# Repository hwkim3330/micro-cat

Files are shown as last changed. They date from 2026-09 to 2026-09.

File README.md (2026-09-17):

# MICRO CAT — Rev 1

**소유자 hwkim3330이 제작·판매를 목표로 개발하는 상업용 독자 설계 소형 두발 로봇.** 둥근 머리, 쉘과 한 몸인 귀, 말려 올라간 꼬리, 뒤로 길어진 앞발. Microduck의 14축 정책 인터페이스(61 관측 → 14 행동, 50 Hz)를 그대로 쓰되 기구·외장·서보 배치·전장 자리는 독자 설계입니다.

관련 저장소: [Micro X](https://github.com/hwkim3330/micro-x)(티렉스 계열, 같은 도구·같은 소유자) · [Micro Rex](https://github.com/hwkim3330/micro-rex)(원본 기구를 그대로 쓰는 **비상업** 비교 시험기) · [micro-cat-fly](https://github.com/hwkim3330/micro-cat-fly)(고정된 초파리 커넥톰으로 목표 방향 명령을 만드는 **비상업** 연구 저장소).

**현재 단계: Rev 1 구동 설계 · 디지털 검증. 실물 출력·조립·보행·내구 시험은 아직 없습니다. 판매 가능한 완제품이 아닙니다.**

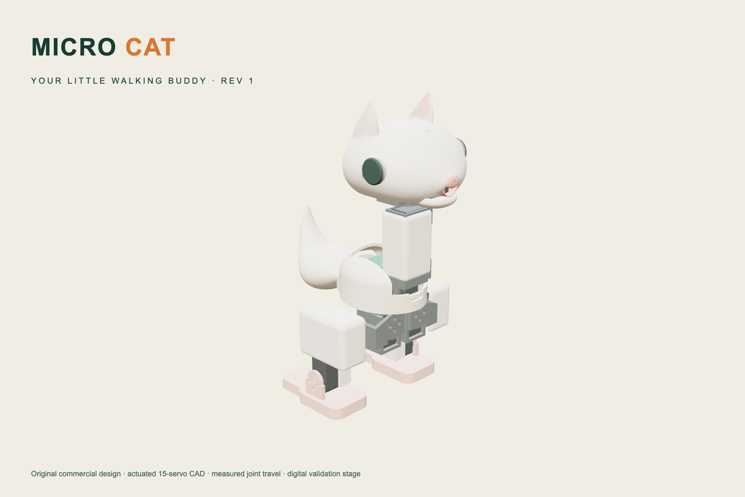
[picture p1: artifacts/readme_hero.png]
Micro Cat Rev 1 — 실제 CAD 렌더


| | |
|---|---|
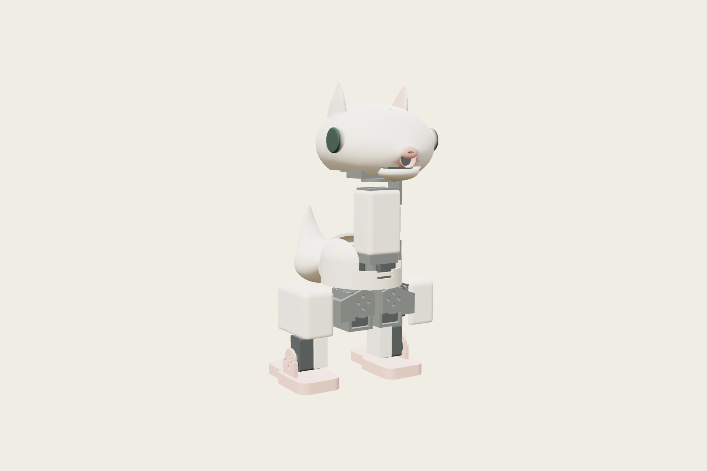
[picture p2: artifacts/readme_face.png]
얼굴
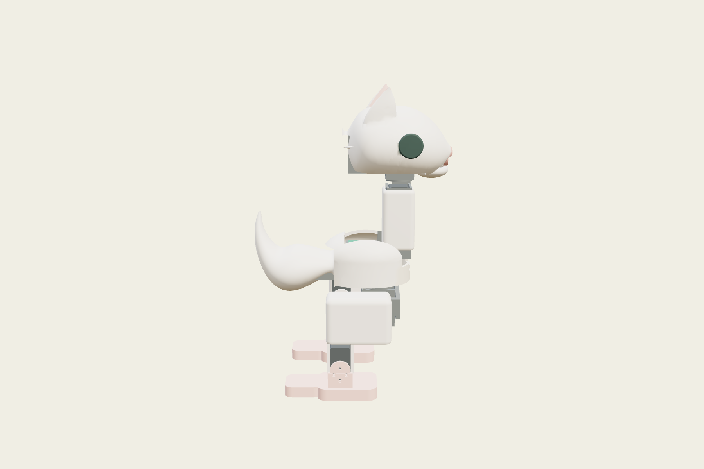
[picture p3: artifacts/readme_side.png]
측면
|  |  |

위 그림은 컨셉 일러스트가 아니라 **실제 CAD를 웹 뷰어로 띄워 촬영한 것**입니다(`tools/portrait.mjs`). 형상을 바꾸면 그림도 같이 바뀝니다.

[제품 페이지 · 3D 뷰어](https://hwkim3330.github.io/micro-cat/web/) · [학습 Lab](https://hwkim3330.github.io/micro-cat/web/lab.html) · [보행 실험](https://hwkim3330.github.io/micro-cat/web/simulator.html) · [설계](docs/DESIGN.md) · [조립](docs/ASSEMBLY.md) · [목표와 진행 기준](PROJECT_GOAL.md)

## 이 저장소가 주장하는 것과 주장하지 않는 것

주장하는 것은 **측정된 것뿐**입니다. 아래 표의 모든 숫자는 `artifacts/`의 JSON에서 `tools/report.py`가 자동으로 채워 넣으며, 모델 SHA256에 묶여 있어 형상을 바꾸면 검사 결과가 먼저 깨집니다. 문서에 손으로 적은 성능 숫자는 없습니다.

주장하지 않는 것: 실물 보행, 내구성, 원가 경쟁력. 특히 원가는 [docs/COST.md](docs/COST.md)에 기록된 대로 **15개 소매 서보 값만으로도 완제품 $399를 넘습니다.** 부품값으로 이기는 물건이 아닙니다.

<!-- measured:summary -->
| 항목 | 값 | 출처 |
|---|---|---|
| 출력 부품 | 20개, 474.7 g (PLA 꽉 찬 기준, 실제 인필은 더 가벼움) | `artifacts/parts.json` |
| 구매품 | 18개, 399.0 g (카탈로그) | 같은 파일 |
| 모델 총질량 · 무게중심 | 872.5 g, 무게중심 z 139.67 mm, 지지영역 여유 16.16 mm | `artifacts/balance.json` |
| 간섭 | 설계 자세 정적 겹침 0건 / 측정 가동 범위 안 스윕 충돌 0 | `artifacts/interference.json` |
| 출력성 | 20개 모두 220×220 침대, 최악 오버행 29 %, 침대 접촉 0 mm² 5개(right_upper_leg, left_upper_leg, skull, neck_sleeve, tail_cover)는 브림/서포트 필요 | `artifacts/printability.json` |
| 공식 가중치 (무수정) | 15회 중 15회 직립, 추종 게이트 6/15 통과 | `artifacts/compat_evaluation.json` |
<!-- /measured -->

## micro-x에서 바뀐 것

| | micro-x Rev C | Micro Cat Rev 1 | 이유 |
|---|---|---|---|
| 형상 | 둥근 머리 + 넓은 부리 | 둥근 두개골 + 짧은 입, 통짜 귀, 말린 꼬리 | 부리를 남기면 계속 오리로 읽힘 |
| 귀 | 없음 | 지붕에서 자라난 통짜 핀 | 별도 부품·얇은 목 없이 실루엣을 만드는 유일한 방법 |
| 앞발 | 평평한 바닥판만 | 같은 바닥판 + **1.0 mm 뜬 뒤꿈치 돌기** (뒤로 32 mm) | 아래 "가장 약한 축" 참조 |
| 고관절 브래킷 윗면 | 평면으로 절단 | **롤 축 ±0.35 rad 회전 포락선**으로 절단 | 평면이면 바깥 리브가 몸통 스커트에 걸려 롤이 +5.7°에서 멈춤 |
| 카메라 | x 70 | x 60 | 두개골을 122 → 108 mm로 줄이기 위해. 대가로 코 보어가 깔때기가 되어 실효 화각 약 60° |
| 발 접촉 박스 | 하드코딩 (x −52…2) | **발바닥 메시에서 산출** | 하드코딩이면 늘린 발이 물리 모델에 반영되지 않음 |

## 가장 약한 축은 "뒤로 넘어짐"이었습니다

HOME 자세에서 무게중심이 지지영역을 벗어나기까지의 정적 각도입니다(`tools/tip_study.py`, 강체·정적·접촉 모델 없음).

<!-- measured:tip -->
| | **Micro Cat** | **Microduck (원본)** | Micro X |
|---|---|---|---|
| **뒤로 기울기** | 17.65° | 8.5° | 5.5° |
| 앞으로 기울기 | 19.25° | 13.25° | 18.0° |
| 옆으로 기울기 | 25.25° | 23.8° | 24.9° |
| 무게중심 높이 (mm) | 135.7 | 141.1 | 138.0 |
| 질량 (g) | 872.5 | 737.2 | 834.3 |

`tools/tip_study.py`: 기울기마다 몸을 회전시켜 바닥에 내려놓고 접촉점을 다시 계산합니다. 원본은 HOME에서 **발바닥이 평평하지 않아** 뒤꿈치 선으로 서 있고, 무게중심이 그 선보다 21 mm 앞에 있어 발끝이 닿을 때까지 앞으로 넘어갑니다. 표의 값은 그렇게 안정된 자세부터 넘어질 때까지의 각도입니다. 강체·정적이며 접촉 강성·마찰·동역학은 없습니다.
<!-- /measured -->

머리가 무겁고 발이 앞으로만 길어서 뒤쪽 지지 거리가 짧습니다. 대응은 바닥판 뒤 32 mm까지 뻗은 **1.0 mm 떠 있는 뒤꿈치 돌기**입니다 — 평지에서는 안 닿고 뒤로 8° 기울면 닿습니다. 바닥판 자체는 기준 발과 같은 58 mm이고, 걸을 때 접촉 면적이 늘지 않습니다.

<!-- measured:spur -->
| 뒤꿈치 돌기 높이 | 맞물림 각도 | 뒤로 기울기 | 여유 |
|---|---|---|---|
| no spur | — | 4.5° | — |
| 0.5 mm | 7.1° | 17.6° | +10.5° |
| 1.0 mm | 7.98° | 17.65° | +9.7° |
| 1.5 mm | 8.85° | 17.7° | +8.8° |

맞물림 각도 = 돌기가 바닥에 닿기 시작하는 뒤쪽 기울기. 여유 = 닿은 뒤로도 더 기울 수 있는 각도이며, **음수면 닿기 전에 넘어져서 돌기가 아무 일도 하지 않습니다.**
<!-- /measured -->

여유가 음수면 **닿기 전에 넘어져서 효과가 0**입니다. 실제로 돌기를 24 mm로 잡았을 때 1.5 mm는 여유 −7.1°로 아무 일도 하지 않았고, 출하하려던 1.0 mm는 그 한 칸 아래였습니다. 32 mm로 늘려 세 높이 전부 여유 9° 이상을 확보했습니다. 이번 설계에서 유일하게 취향이 아니라 측정에 근거한 변경입니다.

### 속도·회전 숫자는 믿지 마세요

<!-- measured:harness -->
| 모델 | 전진 명령 추종 (최대) | 회전 명령 추종 (최대) |
|---|---|---|
| microduck_reference | 45 % | 9 % |
| micro_cat | 25 % | 1 % |

기준 로봇 자신이 자기 명령을 못 따르므로, **이 하네스의 절대 속도·회전 숫자는 설계 근거로 쓸 수 없습니다.** 같은 하네스 안에서의 모델 간 상대 비교만 의미가 있습니다.
<!-- /measured -->

주의: 머리 전장을 몸통으로 옮기는 식의 "무게를 낮춘다" 대응은 몸통 질량중심이 발 중심보다 뒤에 있으면 오히려 뒤쪽을 악화시킵니다. 무게 재배치는 반드시 몸통 **앞쪽**이어야 하고, 뒤꿈치 연장과 세트로만 의미가 있습니다.

## 측정된 가동 범위

`tools/travel.py`가 관절마다 0.05 rad씩 돌려 가며 정확한 STEP 불리언으로 충돌을 찾은 값이고, 그대로 MuJoCo 관절 한계가 됩니다. 좌우가 다른 것은 브래킷이 좌우 대칭이라 회전 방향에 따라 닿는 곳이 다르기 때문입니다.

<!-- measured:travel -->
| 관절 | 왼쪽 | 오른쪽 |
|---|---|---|
| 고관절 요 | -29.8° … +29.8° | -29.8° … +29.8° |
| 고관절 롤 | -22.9° … +20.1° | -20.1° … +22.9° |
| 고관절 피치 | -90.0° … +51.6° | -51.6° … +90.0° |
| 무릎 | -90.0° … +63.0° | -63.0° … +90.0° |
| 발목 | -31.5° … +31.5° | -31.5° … +31.5° |
| 목 피치 | -11.5° … +22.9° | (단일) |
| 머리 피치 | -48.7° … +54.4° | (단일) |
| 머리 요 | -114.6° … +114.6° | (단일) |
| 머리 롤 | -5.7° … +8.6° | (단일) |
| 턱 | +0.0° … +5.7° | (단일) |

탐색 상한: 고관절 요 ±30°, 고관절 롤 ±23°, 고관절 피치 ±90°, 무릎 ±90°, 발목 ±90°, 목 피치 ±60°, 머리 피치 ±90°, 머리 요 ±115°, 머리 롤 ±25°, 턱 ±40°. 상한에 도달한 값은 기구가 아니라 탐색 범위가 끝난 것입니다.
<!-- /measured -->

## 설계 개요

- **관절**: 좌우 고관절 요·롤·피치, 무릎, 발목(10) + 목 피치, 머리 피치·요·롤(4) + 턱(1).
- **피벗·축**: `engineering/functional_layout.json` (기준 로봇을 qpos 0에서 측정한 기능 치수). 서보 몸체 방향만 두 곳에서 바꿨고 이유를 같은 파일에 적었습니다.
- **서보**: XL330급. 인터페이스 치수와 발주 전 확인 항목은 `engineering/actuator_interface.json`. 케이스 홀 패턴은 아직 모델에 없습니다.
- **패키징**: 2S 18650급 배터리는 꼬리 커버 안, 보드(최대 50 × 27 mm)는 고관절 서보 위 데크, 카메라는 코 안.
- **떨어질 부품 없음**: 귀·눈·코는 전부 쉘과 한 몸이고 도색으로 마감합니다. 손·발톱·수염 없음.
- **설계 자세**는 `qpos = 0`(다리를 곧게 편 자세)이라 모든 관절 축이 X·Y·Z에 정렬되고 브래킷이 평평하게 출력됩니다. 정책의 HOME 각도는 기구에 굳히지 않습니다.

## 재생성

```sh
uv venv .venv && uv pip install --python .venv/bin/python -r requirements.txt
.venv/bin/python cad/build.py          # 20개 부품 STEP/STL/GLB + artifacts/parts.json
.venv/bin/python tools/travel.py       # 실측 가동 범위 (수십 분)
.venv/bin/python cad/compat_model.py   # models/micro_cat_14.xml, rig.json, 제어 계약
.venv/bin/python tools/interference.py # 정적 겹침 + 관절별 스윕
.venv/bin/python tools/printability.py # 침대 적합·오버행·접촉 면적
.venv/bin/python tools/balance.py tools/tip_study.py
.venv/bin/python tools/report.py       # 위 결과를 README와 docs/DESIGN.md에 반영
```

정책 평가는 별도 환경입니다:

```sh
uv venv --python 3.12 .venv-policy && uv pip install --python .venv-policy/bin/python -r requirements-policy.txt
.venv-policy/bin/python tools/fetch_compat.py
MUJOCO_GL=disable .venv-policy/bin/python tools/evaluate_compat.py --seconds 10 --seeds 3
```

## 권리

원 설계·CAD·도면·문서: © 2026 hwkim3330, 무단 제조·재배포 금지. 소프트웨어(`tools/`, `runtime/`, `tests/`, `web/`): MIT. 자세한 범위는 [LICENSE](LICENSE)와 [THIRD_PARTY.md](THIRD_PARTY.md).

**Microduck 하드웨어 파일은 이 저장소에 없습니다.** 관절 피벗·축은 출처를 밝힌 기능 치수 측정값이며, 원본 CAD·STL·바디 변환·학습 가중치는 포함하지 않습니다. 원본 기구를 그대로 쓰는 비상업 시험기는 [micro-rex](https://github.com/hwkim3330/micro-rex)에 분리되어 있습니다.

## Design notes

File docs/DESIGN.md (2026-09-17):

# Micro Cat Rev 1 — 설계

좌표계는 mm, X 앞, Y 왼쪽, Z 위, 바닥 Z=0, 몸통 기준 프레임 Z=120입니다. 생성기는 `cad/build.py`, 배치는 `cad/layout.py`, 서보 인터페이스는 `cad/servo.py`, 측정값은 `engineering/functional_layout.json`입니다. 이 문서의 측정 표는 `tools/report.py`가 `artifacts/`에서 채웁니다.

## 물려받은 기구 원칙 (micro-x에서 검증된 것)

1. **설계 자세는 `qpos = 0`** — 다리를 곧게 편 자세에서 치수를 잽니다. HOME(다리가 굽은 자세)에서 재면 모든 피벗 축이 5° 기울어 브래킷마다 사선 형상이 필요합니다. 설계 자세를 곧게 두면 **모든 관절 축이 X·Y·Z에 정렬**되고 브래킷이 단순한 직육면체 조합이 되어 서포트 없이 평평하게 출력됩니다. 정책의 HOME 각도는 기구에 굳히지 않고 그냥 관절 각도로 둡니다.
2. **서보 고정은 단면 방식** — 서보 몸체가 한쪽 링크의 U자 채널에 들어가고, 이웃 링크는 혼에 볼트로 붙는 판 한 장입니다. 관절마다 판 두 장으로 감싸는 클레비스보다 얇고 가볍습니다.
3. **가동 범위는 측정** — `tools/travel.py`가 관절마다 0.05 rad씩 돌려 가며 정확한 STEP 불리언으로 충돌을 찾고, 그 값이 그대로 MuJoCo 관절 한계가 됩니다.

## 구성

| 부위 | 내용 |
|---|---|
| 몸통 | 섀시(바닥판·고관절 요 서보 박스 2개·전장 데크·배터리 트레이) + 알 모양 쉘 |
| 꼬리 | 중심선 접평면 위 단면 7개 로프트. 뒤로 나갔다가 위로 말려 올라가며, 앞쪽 곧은 구간이 배터리 커버 |
| 다리 | 요·롤 브래킷 → 고관절 브래킷 → 허벅지 쉘 → 종아리 → 앞발 |
| 목 | 두 서보가 세로로 쌓인 튜브 + 둥근 커버 |
| 머리 | 요크 → 머리 프레임(머리 롤 + 턱 서보, 카메라 벽, 두개골 보스) → 두개골 로프트 + 아래턱 |

## 고양이로 보이게 만든 것

머리는 **단면 9개 로프트 + 짧은 입 타원체**입니다(x −30…78, 폭 110, 높이 62). micro-x의 부리를 남기면 계속 오리로 읽히기 때문에 부리를 없애고 앞을 뭉툭하게 닫았습니다. 머리를 짧게 만들려고 카메라를 x 70 → 60으로 10 mm 뒤로 옮겼고, 그 대가로 **코 보어가 14 mm 깔때기가 되어 실효 화각이 약 60°**로 모듈 정격보다 좁습니다. 이건 취향이 아니라 맞바꾼 성능이므로 BOM에도 적어 두었습니다.

**귀는 별도 부품이 아닙니다.** 지붕 안쪽(z 276)에서 시작해 z 310까지 올라가는 통짜 테이퍼 핀이라 부러질 목이 없습니다. 안쪽 면은 도색입니다. 눈도 쉘에서 8 mm 뿌리로 솟은 Ø23 버튼이고(테두리가 수직이라 도색 경계가 선명), 코는 렌즈 후드 둘레 도색입니다. **떨어질 부품은 하나도 없습니다** — 수염·발톱·손도 없습니다.

## 가장 약한 축은 뒤로 넘어짐이었습니다

HOME 자세에서 무게중심이 두 발 지지영역을 벗어나기까지의 정적 각도입니다(`tools/tip_study.py`). 강체·정적이고 접촉·마찰·동역학은 없습니다.

<!-- measured:tip -->
| | **Micro Cat** | **Microduck (원본)** | Micro X |
|---|---|---|---|
| **뒤로 기울기** | 17.65° | 8.5° | 5.5° |
| 앞으로 기울기 | 19.25° | 13.25° | 18.0° |
| 옆으로 기울기 | 25.25° | 23.8° | 24.9° |
| 무게중심 높이 (mm) | 135.7 | 141.1 | 138.0 |
| 질량 (g) | 872.5 | 737.2 | 834.3 |

`tools/tip_study.py`: 기울기마다 몸을 회전시켜 바닥에 내려놓고 접촉점을 다시 계산합니다. 원본은 HOME에서 **발바닥이 평평하지 않아** 뒤꿈치 선으로 서 있고, 무게중심이 그 선보다 21 mm 앞에 있어 발끝이 닿을 때까지 앞으로 넘어갑니다. 표의 값은 그렇게 안정된 자세부터 넘어질 때까지의 각도입니다. 강체·정적이며 접촉 강성·마찰·동역학은 없습니다.
<!-- /measured -->

머리가 전체 질량의 큰 몫을 차지하는데 발은 앞으로만 길어서, 뒤쪽 지지 거리가 앞쪽의 3분의 1도 되지 않습니다.

**처음 시도(바닥판을 뒤로 16 mm 연장)는 폐기했습니다.** 접촉 패치가 길어지면 회전을 방해하고(`artifacts/foot_length_sweep.json`), 무엇보다 뒤쪽 지지가 늘어나는 만큼 바닥에 항상 닿아 있어야 해서 얻는 게 없습니다.

채택한 것은 **뜬 뒤꿈치 돌기**입니다. 바닥판은 기준 발과 같은 58 mm(x −54…4)로 두고, 그 뒤 32 mm까지 뻗은 돌기(x −86…−50)를 바닥면보다 **1.0 mm 위**에 둡니다. 평지에서는 닿지 않고, 뒤로 8° 기울면 바닥에 닿아 그때부터 지지점이 됩니다.

<!-- measured:spur -->
| 뒤꿈치 돌기 높이 | 맞물림 각도 | 뒤로 기울기 | 여유 |
|---|---|---|---|
| no spur | — | 4.5° | — |
| 0.5 mm | 7.1° | 17.6° | +10.5° |
| 1.0 mm | 7.98° | 17.65° | +9.7° |
| 1.5 mm | 8.85° | 17.7° | +8.8° |

맞물림 각도 = 돌기가 바닥에 닿기 시작하는 뒤쪽 기울기. 여유 = 닿은 뒤로도 더 기울 수 있는 각도이며, **음수면 닿기 전에 넘어져서 돌기가 아무 일도 하지 않습니다.**
<!-- /measured -->

돌기 뒤쪽 길이가 이 설계의 핵심 변수입니다. 처음에는 24 mm로 잡았는데, 그때는 **1.5 mm 돌기가 닿기 전에 로봇이 먼저 넘어가서 효과가 정확히 0이었고**(여유 −7.1°), 출하하려던 1.0 mm는 그 바로 한 칸 아래였습니다. 무게중심이 조금만 움직여도 무용지물이 되는 자리입니다. 32 mm로 늘리자 세 높이 전부 여유 9° 이상으로 맞물립니다.

이 함정은 계산으로는 안 보입니다. 무게중심을 지지영역에 투영하는 기존 방식은 **닿지도 않는 돌기를 지지점으로 계산해서 효과가 있다고 답합니다.** 준정적 로킹 해석이라야 드러납니다.

남은 위험: 보행 중에 돌기가 바닥을 스치는지는 아래 이유로 아직 못 잽니다.

## 이 저장소가 속도·회전 숫자를 믿지 않는 이유

고정된 공식 추론 코드와 무수정 가중치로 **기준 로봇을 그 로봇 자신의 공식 씬에서** 돌린 결과입니다(`tools/harness_check.py`).

<!-- measured:harness -->
| 모델 | 전진 명령 추종 (최대) | 회전 명령 추종 (최대) |
|---|---|---|
| microduck_reference | 45 % | 9 % |
| micro_cat | 25 % | 1 % |

기준 로봇 자신이 자기 명령을 못 따르므로, **이 하네스의 절대 속도·회전 숫자는 설계 근거로 쓸 수 없습니다.** 같은 하네스 안에서의 모델 간 상대 비교만 의미가 있습니다.
<!-- /measured -->

기준 로봇이 전진 명령의 45 %, 회전 명령의 9 %밖에 못 따르고 1.0 m/s 명령에서는 2.1초에 넘어집니다. 그래서 이 하네스는 **직립·안정성 판정에는 쓰되, 속도·회전 추종을 설계 판단 근거로는 쓰지 않습니다.** 발 길이·뒤꿈치 스윕의 회전 숫자도 같은 이유로 참고용입니다.

반직관적인 점 하나: "머리 전장을 몸통으로 내려 무게중심을 낮춘다"는 대응은 몸통 질량중심이 발 중심보다 뒤에 있으면 **뒤쪽을 오히려 악화시킵니다.** 무게 재배치는 몸통 앞쪽이어야 하고, 뒤꿈치 연장과 세트로만 의미가 있습니다.

## 고관절 롤이 막혀 있던 이유

micro-x는 고관절 브래킷 윗면을 **평면**(z 114.5)으로 잘랐습니다. 그러면 롤을 줄 때 바깥 리브가 올라가 몸통 스커트 밑면(z 116)에 걸려 롤이 **+5.7°**에서 멈춥니다 — 카탈로그 ±23°와 무관하게, 그리고 문서에 적힌 ±17°와도 무관하게 실제로 그렇습니다.

Micro Cat은 윗면을 평면이 아니라 **롤 축을 중심으로 ±0.35 rad 회전시킨 섀시 바닥면의 하한 포락선**으로 깎습니다(`ROLL_SWEEP`). 브래킷은 조금 작아지지만 롤이 탐색 상한까지 열립니다.

## 측정된 가동 범위

<!-- measured:travel -->
| 관절 | 왼쪽 | 오른쪽 |
|---|---|---|
| 고관절 요 | -29.8° … +29.8° | -29.8° … +29.8° |
| 고관절 롤 | -22.9° … +20.1° | -20.1° … +22.9° |
| 고관절 피치 | -90.0° … +51.6° | -51.6° … +90.0° |
| 무릎 | -90.0° … +63.0° | -63.0° … +90.0° |
| 발목 | -31.5° … +31.5° | -31.5° … +31.5° |
| 목 피치 | -11.5° … +22.9° | (단일) |
| 머리 피치 | -48.7° … +54.4° | (단일) |
| 머리 요 | -114.6° … +114.6° | (단일) |
| 머리 롤 | -5.7° … +8.6° | (단일) |
| 턱 | +0.0° … +5.7° | (단일) |

탐색 상한: 고관절 요 ±30°, 고관절 롤 ±23°, 고관절 피치 ±90°, 무릎 ±90°, 발목 ±90°, 목 피치 ±60°, 머리 피치 ±90°, 머리 요 ±115°, 머리 롤 ±25°, 턱 ±40°. 상한에 도달한 값은 기구가 아니라 탐색 범위가 끝난 것입니다.
<!-- /measured -->

턱은 여전히 좁습니다. 턱 피벗이 머리 요크 앞면(x 39.4) 바로 옆이라 혼 판이 곧바로 요크에 닿습니다. 혼 판 폭을 20 → 13 mm로 줄여도 바뀌지 않았고, **요크를 다시 그려야 풀립니다.** 다음 개선 대상입니다.

머리 프레임을 그릴 때 주의: 앞쪽 빔과 두개골 앞 보스가 요크 앞면(x 39.4)에서 2 mm 이상 떨어져야 합니다. 처음 그렸을 때 보스를 x 42에 두어 **정지 상태에서 195 mm³ 겹쳤고, 머리 롤이 0°가 되었습니다.**

## 출력과 검증

<!-- measured:summary -->
| 항목 | 값 | 출처 |
|---|---|---|
| 출력 부품 | 20개, 474.7 g (PLA 꽉 찬 기준, 실제 인필은 더 가벼움) | `artifacts/parts.json` |
| 구매품 | 18개, 399.0 g (카탈로그) | 같은 파일 |
| 모델 총질량 · 무게중심 | 872.5 g, 무게중심 z 139.67 mm, 지지영역 여유 16.16 mm | `artifacts/balance.json` |
| 간섭 | 설계 자세 정적 겹침 0건 / 측정 가동 범위 안 스윕 충돌 0 | `artifacts/interference.json` |
| 출력성 | 20개 모두 220×220 침대, 최악 오버행 29 %, 침대 접촉 0 mm² 5개(right_upper_leg, left_upper_leg, skull, neck_sleeve, tail_cover)는 브림/서포트 필요 | `artifacts/printability.json` |
| 공식 가중치 (무수정) | 15회 중 15회 직립, 추종 게이트 6/15 통과 | `artifacts/compat_evaluation.json` |
<!-- /measured -->

부품마다 출력 방향이 `models/print/`에 고정되어 있습니다. 대부분의 브래킷은 면 하나를 침대에 붙이고 벽이 전부 수직이라 서포트가 필요 없습니다. 침대 접촉 면적이 0 mm²인 부품은 브림 또는 서포트가 필요합니다.

공식 가중치 시험의 전진 명령 추종 미달은 **원본 Microduck 모델에 같은 하네스를 돌려도 나타납니다**(micro-rex의 `tools/evaluate_policy.py`). 고양이 기구만의 결함으로 해석하지 않습니다.

## 남은 일

- 턱 가동 범위: 요크 재설계.
- 서보 케이스 홀 확인 후 몸체 고정 나사 추가, 케이블 경로(목·머리 4축, 다리 5축).
- IMU·마이크·스피커·전원 보드 배치(데크는 50 × 27 mm까지).
- 출력 공차 시편 → 다리 한 쪽 → 전체 조립 → 낙하·피로·발열 → 보행 시험.
- 공급업체 견적, DFM, 권리 검토.

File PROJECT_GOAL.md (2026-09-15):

# Micro Cat product design goal

Owner: hwkim3330. A commercial, independently designed cat-shaped companion biped that keeps
the Microduck 14-axis policy interface (61 observations to 14 actions at 50 Hz) so the public
pretrained weights load unchanged.

## Why a separate repository

- `micro-rex` vendors Microduck hardware files (CC BY-SA-NC) and therefore stays noncommercial.
  Nothing in this repository may depend on it.
- `micro-x` is the T-rex line. Three appearance revisions there were rejected as not cute enough
  and the cost study showed it could not undercut a $399 complete robot. Micro Cat restarts the
  appearance from a cat, and carries over only the parts of that work that were measured and held
  up: the design-pose layout, the single-sided servo mounting, and the measurement tools.
- This repository contains no Microduck CAD, STL, body transforms, trained policies or
  hardware-derived model data. Joint pivots and axes are attributed functional measurements.

## What is carried over, and what is new

Carried over from micro-x (same owner, same toolchain):
- design pose at `qpos = 0` (straight legs), so every joint axis is world-aligned and brackets print flat;
- servo held by a U-channel in one link driving a single horn plate on the next;
- measured, not declared, joint travel (`tools/travel.py`), printability, interference and balance tools;
- the CAD-derived 14-axis MuJoCo model and the Lab/simulator web stack.

New in Micro Cat:
- round cat cranium with a short muzzle, solid printed ears, nose lens hood, button eyes;
- a tail that curls up and still works as the battery cover;
- paws whose soles reach 16 mm further back than the reference foot. This is the one change
  driven by a measurement rather than by taste: on the stock reference robot, backward tipping
  is the weakest static axis (6.7 deg, versus 11.9 forward and 23.0 lateral), and the aft support
  reach is what sets it. See `docs/DESIGN.md`.

## Acceptance and limits

- Every printable part is a valid closed CAD solid and a watertight mesh; the design pose has no
  exact-STEP overlaps; per-joint sweeps inside the measured travel are recorded.
- Servo interface dimensions are purchased-part data. Case hole pattern, cable exits and the
  voltage rail must be confirmed before ordering.
- Static CAD, simulated uprightness and ONNX loading are not walking acceptance. Acceptance needs
  measured velocity and yaw tracking, fall rates and reproducible training, then physical trials.
- The cost model uses retail servo pricing and stated assumptions. It is not a quote, and the
  recorded conclusion from micro-x still stands: 15 retail XL330-class servos alone exceed the
  price of a complete $399 robot. Anything sold here has to be justified on something other than
  beating that number on parts cost.

## Completion ledger

- [x] Rev 1 actuated cat CAD: 20 printed parts, 15 servo envelopes, battery/board/camera placement
- [ ] Measured travel, interference, printability and balance regenerated for the cat geometry
- [ ] CAD-derived 14-axis model; unchanged official weights evaluated on it
- [ ] Product page, Lab and simulator rebuilt on the cat rig
- [ ] Servo case retention and cable routing
- [ ] Printed coupons, one leg, full assembly; fit, endurance, drop and thermal tests
- [ ] Walking acceptance in simulation, then on hardware
- [ ] Supplier quotes, DFM, market and rights review before any sale

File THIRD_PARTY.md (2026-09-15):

# Third-party software

- Three.js 0.180.0, MIT, bundled under web/vendor/three/. Upstream license retained as LICENSE. Source: https://github.com/mrdoob/three/tree/r180
- CadQuery 2.8.0 (Apache-2.0), Open CASCADE via cadquery-ocp, trimesh 4.11.1 (MIT), NumPy (BSD), ReportLab (BSD): build-time dependencies, not bundled in the website. Their licenses are not automatically assigned to original generated designs.
- Puppeteer 25.10.0 (Apache-2.0): test-time dependency.

No upstream Microduck mesh, CAD or hardware XML is included. Functional joint measurements are attributed in engineering/functional_interface.json. Pinned Apache-2.0 inference software and policy weights are fetched into the excluded local cache by tools/fetch_compat.py; engineering/policy_sources.json records hashes and license sources. The official mjlab training environment is installed separately under its own licenses. These software licenses do not relicense upstream hardware.

Camera mounting dimensions reference the Raspberry Pi Camera Module 3 Standard manufacturer drawing . No manufacturer drawing or CAD is bundled. rpicam-apps and ALSA utilities are external system dependencies, not distributed here. The original synthesized chirp and runtime source are MIT under the root LICENSE scope.

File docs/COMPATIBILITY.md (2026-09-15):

# 14축 정책 호환 검증 (Rev A)

목표는 **독자 설계 상업용 Micro Cat가 Microduck의 정책 인터페이스(61 관측 → 14 행동, 50 Hz)를 그대로 쓰는 것**입니다. 원본 CAD로 돌아가거나 비상업 하드웨어를 재라이선스하는 것이 아닙니다.

## 세 층

1. **Rev B CAD** (`cad/build.py`): 20개 출력 부품 + 15개 서보·배터리·보드·카메라 외형. 관절 피벗·축은 `engineering/functional_layout.json`(기준 로봇을 qpos 0에서 측정한 기능 치수)을 따르고 나머지는 새로 설계.
2. **CAD 기반 동역학 모델** (`cad/compat_model.py` → `models/micro_cat_14.xml`): 부품 메시에서 링크별 질량·질량중심·관성을 계산(PLA 꽉 찬 밀도 + 구매품 카탈로그 질량). 관절 한계는 추측이 아니라 `tools/travel.py`가 측정한 실제 가동 범위입니다. 몸통 프레임은 기준 로봇과 같은 120 mm 높이이고, HOME 기립 높이는 119.3 mm입니다. 이전의 원시 도형 연구 모델은 `models/archive/micro_cat_14_primitive_study.xml`로 보존.
3. **고정된 공식 추론 코드 + 가중치** (`runtime/compat_env.py`, `.cache/compat/`): 변경 없는 `alpha_walking.onnx`/`alpha_stand.onnx`와 BAM M6 XL330 모터 모델(kp 200, 7.4 V 재현 조건).

## 제어 계약

`engineering/control_interface.json`: 14 액추에이터 이름·순서, HOME 오프셋, 61 관측(자이로 3, 투영 중력 3, HOME 상대 관절 위치 14, 관절 속도 14, 이전 행동 14, 명령 13), 50 Hz 제어 / 200 Hz 물리. 목표 = HOME + 행동, 스케일 1. 턱은 15번째 수동 관절(정책 외)로 모델에 포함되며 `models/rig.json`이 qpos 배열 순서를 기록합니다.

Rev B의 관절 한계는 `engineering/joint_travel.json`의 측정값입니다: 고관절 요 -26°…+30°, 롤 -20°…+17°, 피치 -90°…+63°, 무릎 -90°…+63°, 발목 ±52°, 목 피치 -12°…+40°, 머리 피치 ±34°, 요 ±115°, 롤 ±17°, 턱 0°…+17° (좌우 비대칭). 정책이 그 이상을 명령하면 시뮬레이션에서 관절 한계에 걸립니다.

## 시험 프로토콜

`tools/evaluate_compat.py`: 정지, 전진 0.1 / 0.3 m/s, 회전 0.3 rad/s 명령 × 시드, 각 N초. 넘어짐 = 몸통 기울기 45° 초과 또는 높이 65 mm 미만. 1초 워밍업 후 몸체 좌표 속도 MAE. 통과 = 넘어짐 없음, 전진 MAE ≤ max(0.03, 명령의 25 %), 좌우 ≤ 0.03, 요 ≤ 0.10. 학습 체크포인트는 `--walking-policy`로 같은 프로토콜에 넣습니다(Lab의 "평가 실행").

## 현재 결과

- `artifacts/compat_evaluation.json`: CAD 기반 모델에 변경 없는 공식 가중치. 결과 요약은 Lab 14축 학습 탭의 첫 카드와 `README.md`에 있으며, 모델 SHA256이 파일에 묶여 있어 모델을 바꾸면 테스트가 실패합니다.
- `artifacts/compat_training.json`: 같은 액터를 CPU PPO로 짧게 이어 학습·ONNX 재내보내기 (파이프라인 검증).
- 이전 원시 연구 모델의 기록(`compat_heldout_evaluation.json`, `training_500.json`, `trained_500_evaluation.json`, `official_recipe_x_validation.json`)은 아카이브 모델 SHA256에 묶여 보존됩니다.

원본 Microduck 모델에 같은 프로토콜을 돌린 비교값은 [micro-rex](https://github.com/hwkim3330/micro-rex)의 `tools/evaluate_policy.py`가 만듭니다. 두 결과를 나란히 읽어야 "가중치 호환"의 의미가 정해집니다: 원본에서도 이 하네스의 전진 명령 추종은 미달이므로, X의 미달을 X 기구만의 문제로 보지 않습니다.

## 재현

```sh
uv venv --python 3.12 .venv-policy && uv pip install --python .venv-policy/bin/python -r requirements-policy.txt
.venv-policy/bin/python tools/fetch_compat.py
.venv/bin/python cad/build.py && .venv/bin/python cad/compat_model.py
.venv-policy/bin/python tools/evaluate_compat.py --seconds 10 --seeds 3
.venv-policy/bin/python tools/train_compat.py --updates 10 --steps 256
.venv-policy/bin/python runtime/training_service.py   # Lab에서 학습·평가·재생
```

실물 호환(전압 5 V 재보정, 실제 관성, 케이블, 접촉)과 생산 준비는 별도 미해결 과제입니다.

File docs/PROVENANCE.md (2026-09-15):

# Provenance and commercial boundaries

This is a newly initialized repository, not a fork of Microduck or the Micro Rex retrofit or the Micro X repository (same owner, shared tooling, independent geometry). `cad/build.py` constructs geometry from explicit dimensions using CadQuery primitives and lofts; it reads no external robot geometry. Body outlines, joint display pivots and part splits originate in this file. The developer previously inspected Microduck sources, so this is not represented as a formal clean-room legal process.

The old Micro Rex geometry stays in its separate repository. Its pinned upstream Microduck RL README states hardware designs are CC BY-SA-NC, without a version in that notice:
https://raw.githubusercontent.com/pollen-robotics/microduck_rl/2b25a48b08f1f17bc38c90bb03144c81fbd9ed07/README.md

No conversion of those rights to a commercial license is attempted. The general NC restriction is described by Creative Commons at https://creativecommons.org/licenses/by-nc-sa/4.0/ ; that page does not determine the unspecified version of the upstream notice.

Original design data including parametric CAD source is reserved for the owner under the root LICENSE. Software utilities and web application logic are MIT. Three.js is MIT and retains its upstream text. Public GitHub access is not an additional manufacturing grant. This is a chosen publication policy, not a legal opinion establishing ownership or freedom to operate. Micro Cat is a working name; trademark/design/patent searches and supplier rights review remain product launch gates.

## Supplier research, accessed 2026-09-08

- ROBOTIS XL330-M288 official manual: https://emanual.robotis.com/docs/en/dxl/x/xl330-m288/ . Used for candidate comparison only. No CAD copied.
- Waveshare ST3215 family product page: https://www.waveshare.com/product/modules/st3215-servo.htm . Listed family price $16.99–21.99, different voltage variants; not a negotiated quote or a validated actuator selection. Do not assume the same voltage/torque for every variant.
- FEETECH SCS0009 manufacturer PDF links were located but retrieval failed. No dimensional or torque claims from those unread files were used in this CAD.
- Pollen Robotics Robot HAT repository is Apache-2.0, unlike the noncommercial mechanical model: https://github.com/pollen-robotics/elec_RPI_Robot_HAT . Not bundled or integrated here.

None of the supplier names imply partnership, endorsement or manufacturing approval.

## Functional interoperability measurements

The separate 14-axis study uses joint pivots at HOME (rounded to 0.1 mm) and axes measured from the reference model. `engineering/functional_interface.json` records attribution and the source hash. These measurements are not claimed as exclusive original X artwork. X study surfaces, primitive links, masses and inertias are authored separately; no original hardware meshes or XML are redistributed as X. This is not a legal clearance opinion or relicensing of upstream hardware. The earlier P0-only provenance descriptions do not describe this separate dynamics study.

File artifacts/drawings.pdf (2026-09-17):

# MICRO CAT Rev 1 — printed part reference drawings

Actuated chibi cat; 14 policy joints + jaw. Millimetres. Design pose (straight legs). Assembly frame: X forward, Y left, Z up, floor Z=0, trunk frame Z=120. 20 printed parts (474.7 g solid PLA equivalent) + 18 purchased items (399.0 g catalogue).
Overall views generated from the actual meshes; use STEP for exact geometry. Not production GD&T; prototype fit and fastener checks are still required.

## Printed parts

left_yaw2roll | link left_yaw2roll | 32.4 x 26.8 x 40.4 mm 17.0 g
left_hip | link left_hip | 33.5 x 38.1 x 29.3 mm | 6.3 g
left_upper_leg | link left_upper_leg | 62.2 x 31.8 x 44.5 mm 23.1 g
left_lower_leg | link left_lower_leg | 26.8 x 14.4 x 62.5 mm | 8.6 g
left_foot | link left_foot | 90.0 x 46.0 x 38.0 mm 38.7 g
right_yaw2roll | link right_yaw2roll | 32.4 x 26.8 x 40.4 mm 17.0 g
right_hip | link right_hip | 33.5 x 38.1 x 29.3 mm | 6.3 g
right_upper_leg | link right_upper_leg 62.2 x 31.8 x 44.5 mm 23.1 g
right_lower_leg | link right_lower_leg 26.8 x 14.4 x 62.5 mm | 8.6 g
right_foot | link right_foot | 90.0 x 46.0 x 38.0 mm 38.7 g
chassis | link trunk | 131.0 x 62.0 x 46.5 mm 44.2 g
torso_shell | link trunk | 86.0 x 77.2 x 47.8 mm 29.1 g
tail_cover | link trunk | 81.1 x 66.4 x 81.6 mm 42.6 g
neck_link | link neck | 24.8 x 31.4 x 71.7 mm 16.0 g
neck_sleeve | link neck | 31.6 x 36.8 x 60.4 mm 17.2 g
head_base | link head_base | 26.0 x 35.0 x 25.1 mm | 4.4 g
head_yoke | link head_yoke | 31.3 x 37.8 x 32.4 mm 15.4 g
head_frame | link head | 84.2 x 61.9 x 41.7 mm 25.1 g
skull | link head | 108.0 x 112.0 x 85.9 mm 86.5 g
jaw_chin | link jaw | 58.0 x 40.0 x 32.0 mm | 7.0 g

## Purchased items (envelopes)

servo_left_hip_yaw | actuator link trunk | 18.0 g XL330-class smart servo envelope; confirm the case hole pattern before
servo_left_hip_roll | actuator link left_yaw2roll | 18.0 g XL330-class smart servo envelope; confirm the case hole pattern before
servo_left_hip_pitch actuator link left_upper_leg 18.0 g XL330-class smart servo envelope; confirm the case hole pattern before
servo_left_knee | actuator link left_upper_leg 18.0 g XL330-class smart servo envelope; confirm the case hole pattern before
servo_left_ankle | actuator link left_lower_leg 18.0 g XL330-class smart servo envelope; confirm the case hole pattern before
servo_right_hip_yaw | actuator link trunk | 18.0 g XL330-class smart servo envelope; confirm the case hole pattern before
servo_right_hip_roll actuator link right_yaw2roll 18.0 g XL330-class smart servo envelope; confirm the case hole pattern before servo_right_hip_pitch actuator link right_upper_leg 18.0 g XL330-class smart servo envelope; confirm the case hole pattern before
servo_right_knee | actuator link right_upper_leg 18.0 g XL330-class smart servo envelope; confirm the case hole pattern before
servo_right_ankle | actuator link right_lower_leg 18.0 g XL330-class smart servo envelope; confirm the case hole pattern before
servo_neck_pitch | actuator link neck | 18.0 g XL330-class smart servo envelope; confirm the case hole pattern before
servo_head_pitch | actuator link neck | 18.0 g XL330-class smart servo envelope; confirm the case hole pattern before
servo_head_yaw | actuator link head_yoke | 18.0 g XL330-class smart servo envelope; confirm the case hole pattern before
servo_head_roll | actuator link head | 18.0 g XL330-class smart servo envelope; confirm the case hole pattern before
servo_jaw | actuator link head | 18.0 g XL330-class smart servo envelope; confirm the case hole pattern before
battery_pack | battery | link trunk | 95.0 g Removable 2S 18650 pack, 65 x 37 x 19 mm class, 7.4 V ~3000 mAh; slide
compute_board | electronics link trunk | 30.0 g Single-board computer, compact bay: 26.5 x 47 mm. Boards: board to be
camera_module_3 | camera | link head | 4.0 g Raspberry Pi Camera Module 3 Standard class, 25 x 24 mm board; the nos

# MICRO CAT Rev 1 / left_yaw2roll

link: left_yaw2roll | millimetres | original design, prototype reference, not production released

SIDE X-Z

Overall: 32.40 x 40.40 mm

TOP X-Y

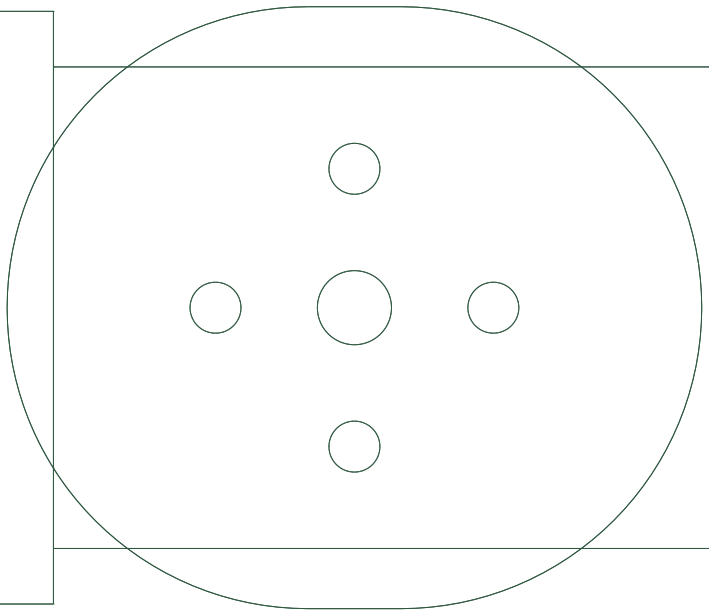
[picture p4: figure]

Overall: 32.40 x 26.80 mm

FRONT Y-Z

Overall: 26.80 x 40.40 mm

Assembly-frame extents X/Y/Z: 32.4 / 26.8 / 40.4 mm
Material volume: 13731.2 mm3 | PLA solid-equivalent: 17.03 g (slicer mass will be lower)

Hip yaw horn plate on a U-channel around the hip roll servo. Print on the plate face; every wall is vertical.
Use STEP for exact geometry. Clearance, fastening, interference and physical fit require prototype verification. Rights: root LICENSE.

# MICRO CAT Rev 1 / left_hip

link: left_hip | millimetres | original design, prototype reference, not production released

SIDE X-Z

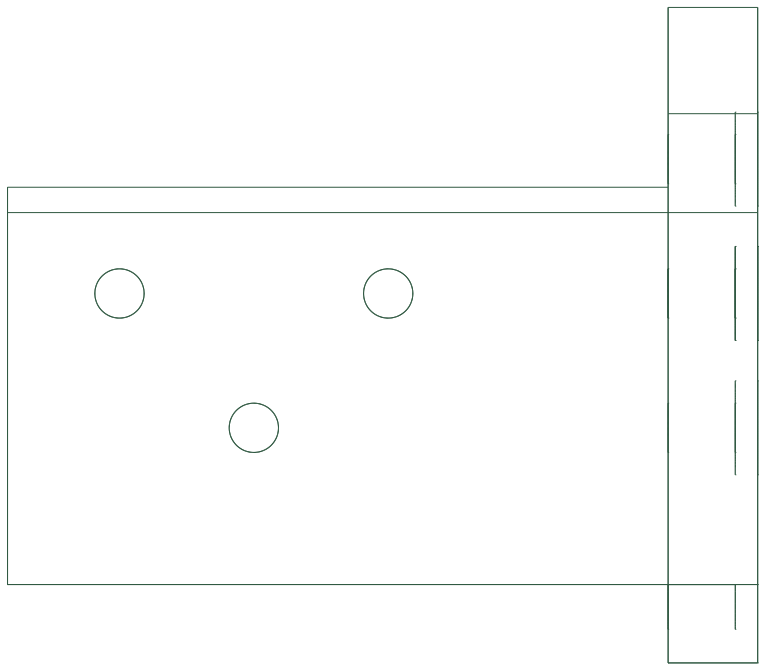
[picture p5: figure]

Overall: 33.50 x 29.27 mm

TOP X-Y

Overall: 33.50 x 38.10 mm

FRONT Y-Z

Overall: 38.10 x 29.27 mm

Assembly-frame extents X/Y/Z: 33.5 / 38.1 / 29.27 mm
Material volume: 5061.1 mm3 | PLA solid-equivalent: 6.28 g (slicer mass will be lower)

Hip corner bracket: roll horn plate and pitch horn plate joined by one rib. Print on the pitch plate face.
Use STEP for exact geometry. Clearance, fastening, interference and physical fit require prototype verification. Rights: root LICENSE.

# MICRO CAT Rev 1 / left_upper_leg

link: left_upper_leg | millimetres | original design, prototype reference, not production released

SIDE X-Z

Overall: 62.20 x 44.50 mm

TOP X-Y

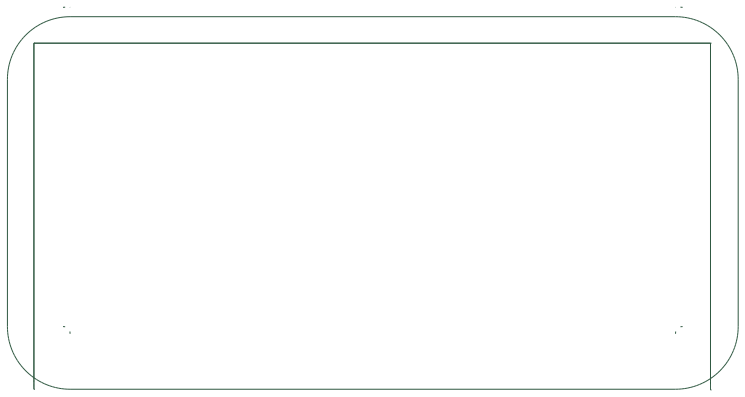
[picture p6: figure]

Overall: 62.20 x 31.75 mm

FRONT Y-Z

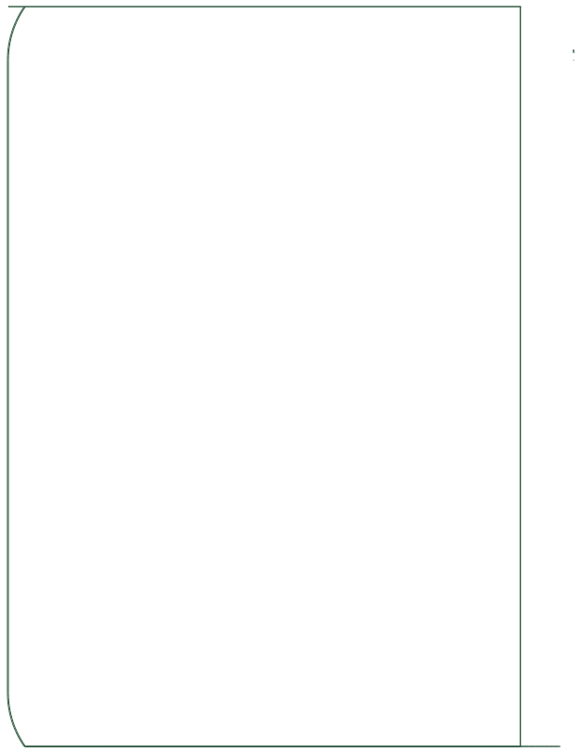
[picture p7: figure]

Overall: 31.75 x 44.50 mm

Assembly-frame extents X/Y/Z: 62.2 / 31.75 / 44.5 mm
Material volume: 18593.5 mm3 | PLA solid-equivalent: 23.06 g (slicer mass will be lower)

Thigh shell around the hip pitch and knee servos, open on the inboard face. Print on the outboard face; the cavity opens upward, no support. Use STEP for exact geometry. Clearance, fastening, interference and physical fit require prototype verification. Rights: root LICENSE.

# MICRO CAT Rev 1 / left_lower_leg

link: left_lower_leg | millimetres | original design, prototype reference, not production released

SIDE X-Z

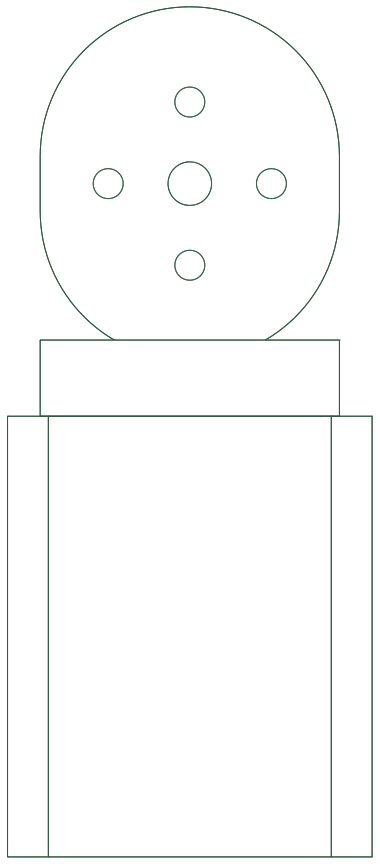
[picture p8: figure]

Overall: 26.80 x 62.50 mm

TOP X-Y

Overall: 26.80 x 14.40 mm

FRONT Y-Z

Overall: 14.40 x 62.50 mm

Assembly-frame extents X/Y/Z: 26.8 / 14.4 / 62.5 mm
Material volume: 6898.7 mm3 | PLA solid-equivalent: 8.55 g (slicer mass will be lower)

Shin: knee horn plate stepping down into a channel around the ankle servo. Print on the inboard face.
Use STEP for exact geometry. Clearance, fastening, interference and physical fit require prototype verification. Rights: root LICENSE.

# MICRO CAT Rev 1 / left_foot

link: left_foot | millimetres | original design, prototype reference, not production released

SIDE X-Z

Overall: 90.00 x 38.00 mm

TOP X-Y

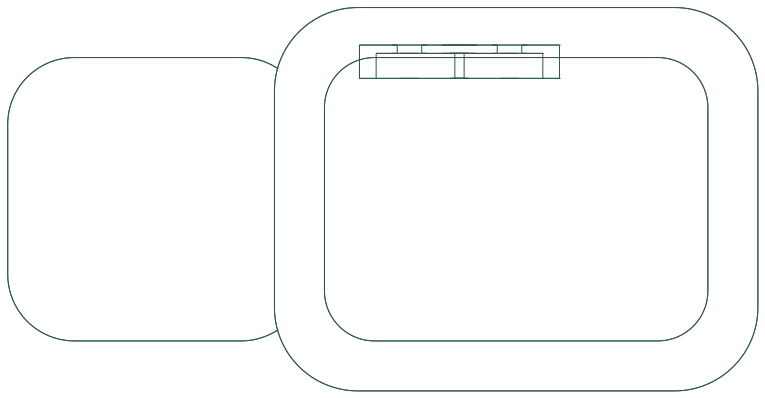
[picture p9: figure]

Overall: 90.00 x 46.00 mm

FRONT Y-Z

Overall: 46.00 x 38.00 mm

Assembly-frame extents X/Y/Z: 90.0 / 46.0 / 38.0 mm
Material volume: 31227.4 mm3 | PLA solid-equivalent: 38.72 g (slicer mass will be lower)

Paw: ankle horn plate on a rounded sole, hollow underneath for a replaceable pad, plus a heel spur that sits 1.5 mm above the sole plane and reaches 24 mm behind it. Print sole down; the spur underside is a bridge 1.5 mm off the bed.
Use STEP for exact geometry. Clearance, fastening, interference and physical fit require prototype verification. Rights: root LICENSE.

# MICRO CAT Rev 1 / right_yaw2roll

link: right_yaw2roll | millimetres | original design, prototype reference, not production released

SIDE X-Z

Overall: 32.40 x 40.40 mm

TOP X-Y

Overall: 32.40 x 26.80 mm

FRONT Y-Z

Overall: 26.80 x 40.40 mm

Assembly-frame extents X/Y/Z: 32.4 / 26.8 / 40.4 mm
Material volume: 13731.2 mm3 | PLA solid-equivalent: 17.03 g (slicer mass will be lower)

Hip yaw horn plate on a U-channel around the hip roll servo. Print on the plate face; every wall is vertical.
Use STEP for exact geometry. Clearance, fastening, interference and physical fit require prototype verification. Rights: root LICENSE.

# MICRO CAT Rev 1 / right_hip

link: right_hip | millimetres | original design, prototype reference, not production released

SIDE X-Z

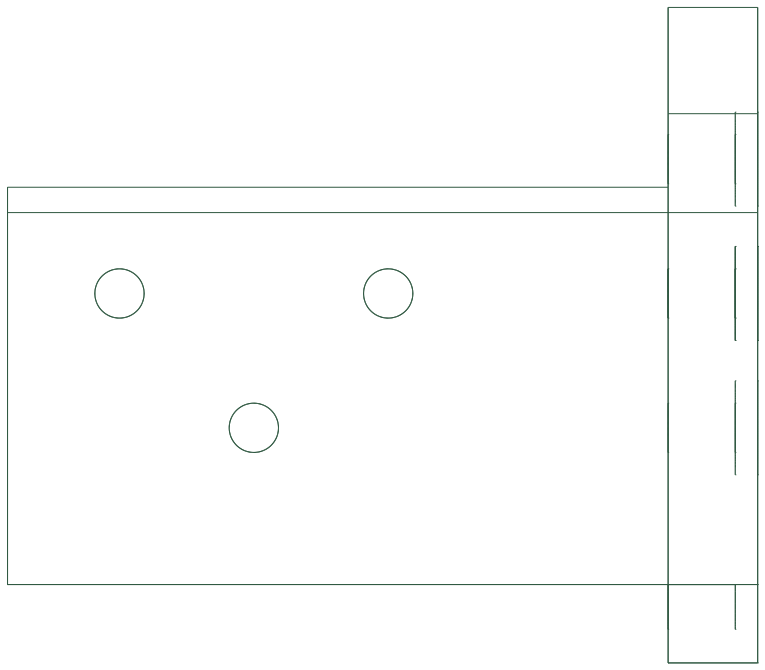
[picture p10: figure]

Overall: 33.50 x 29.27 mm

TOP X-Y

Overall: 33.50 x 38.10 mm

FRONT Y-Z

Overall: 38.10 x 29.27 mm

Assembly-frame extents X/Y/Z: 33.5 / 38.1 / 29.27 mm
Material volume: 5061.1 mm3 | PLA solid-equivalent: 6.28 g (slicer mass will be lower)

Hip corner bracket: roll horn plate and pitch horn plate joined by one rib. Print on the pitch plate face.
Use STEP for exact geometry. Clearance, fastening, interference and physical fit require prototype verification. Rights: root LICENSE.

# MICRO CAT Rev 1 / right_upper_leg

link: right_upper_leg | millimetres | original design, prototype reference, not production released

SIDE X-Z

Overall: 62.20 x 44.50 mm

TOP X-Y

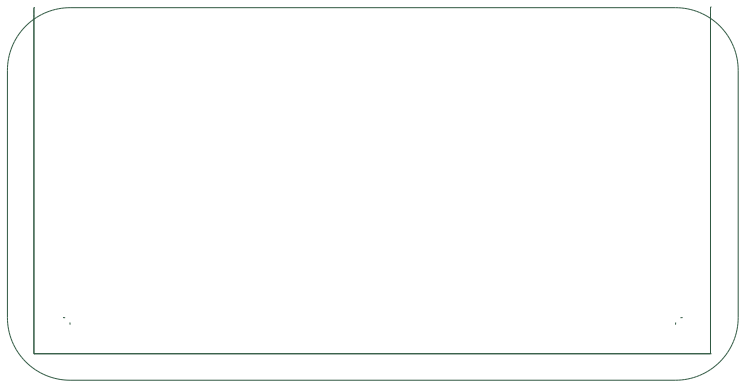
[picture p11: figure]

Overall: 62.20 x 31.75 mm

FRONT Y-Z

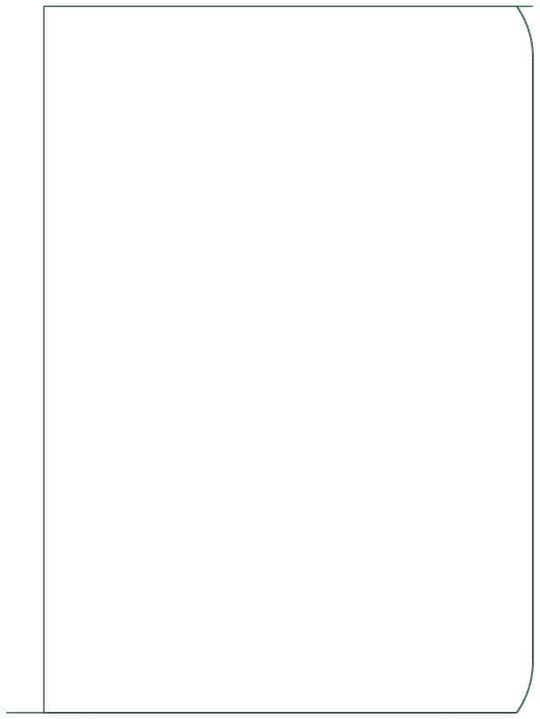
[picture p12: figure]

Overall: 31.75 x 44.50 mm

Assembly-frame extents X/Y/Z: 62.2 / 31.75 / 44.5 mm
Material volume: 18593.5 mm3 | PLA solid-equivalent: 23.06 g (slicer mass will be lower)

Thigh shell around the hip pitch and knee servos, open on the inboard face. Print on the outboard face; the cavity opens upward, no support. Use STEP for exact geometry. Clearance, fastening, interference and physical fit require prototype verification. Rights: root LICENSE.

# MICRO CAT Rev 1 / right_lower_leg

link: right_lower_leg | millimetres | original design, prototype reference, not production released

SIDE X-Z

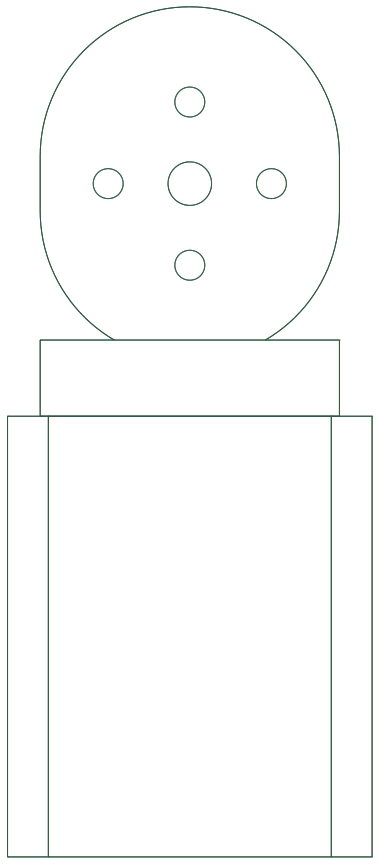
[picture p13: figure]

Overall: 26.80 x 62.50 mm

TOP X-Y

Overall: 26.80 x 14.40 mm

FRONT Y-Z

Overall: 14.40 x 62.50 mm

Assembly-frame extents X/Y/Z: 26.8 / 14.4 / 62.5 mm
Material volume: 6898.7 mm3 | PLA solid-equivalent: 8.55 g (slicer mass will be lower)

Shin: knee horn plate stepping down into a channel around the ankle servo. Print on the inboard face.
Use STEP for exact geometry. Clearance, fastening, interference and physical fit require prototype verification. Rights: root LICENSE.

# MICRO CAT Rev 1 / right_foot

link: right_foot | millimetres | original design, prototype reference, not production released

SIDE X-Z

Overall: 90.00 x 38.00 mm

TOP X-Y

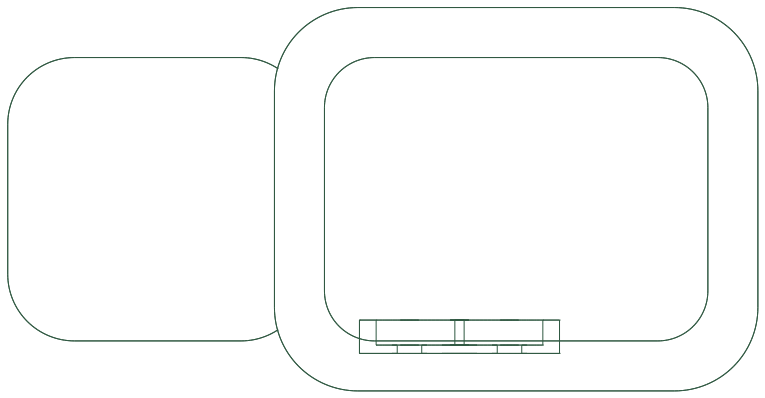
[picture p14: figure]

Overall: 90.00 x 46.00 mm

FRONT Y-Z

Overall: 46.00 x 38.00 mm

Assembly-frame extents X/Y/Z: 90.0 / 46.0 / 38.0 mm
Material volume: 31227.4 mm3 | PLA solid-equivalent: 38.72 g (slicer mass will be lower)

Paw: ankle horn plate on a rounded sole, hollow underneath for a replaceable pad, plus a heel spur that sits 1.5 mm above the sole plane and reaches 24 mm behind it. Print sole down; the spur underside is a bridge 1.5 mm off the bed.
Use STEP for exact geometry. Clearance, fastening, interference and physical fit require prototype verification. Rights: root LICENSE.

# MICRO CAT Rev 1 / chassis

link: trunk | millimetres | original design, prototype reference, not production released

SIDE X-Z

Overall: 131.00 x 46.50 mm

TOP X-Y

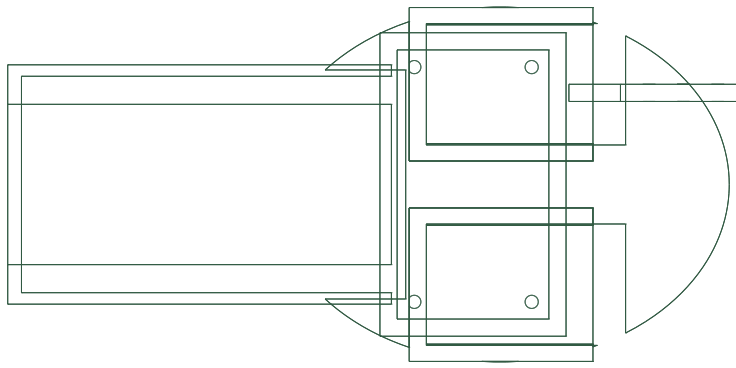
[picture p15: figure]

Overall: 131.00 x 61.98 mm

FRONT Y-Z

Overall: 61.98 x 46.50 mm

Assembly-frame extents X/Y/Z: 131.0 / 61.98 / 46.5 mm
Material volume: 35653.3 mm3 | PLA solid-equivalent: 44.21 g (slicer mass will be lower)

Chassis: floor with two hip-yaw servo boxes, neck horn plate, battery tray and compute board wall. Print floor down; the servo boxes bridge 21 mm. Use STEP for exact geometry. Clearance, fastening, interference and physical fit require prototype verification. Rights: root LICENSE.

# MICRO CAT Rev 1 / torso_shell

link: trunk | millimetres | original design, prototype reference, not production released

SIDE X-Z

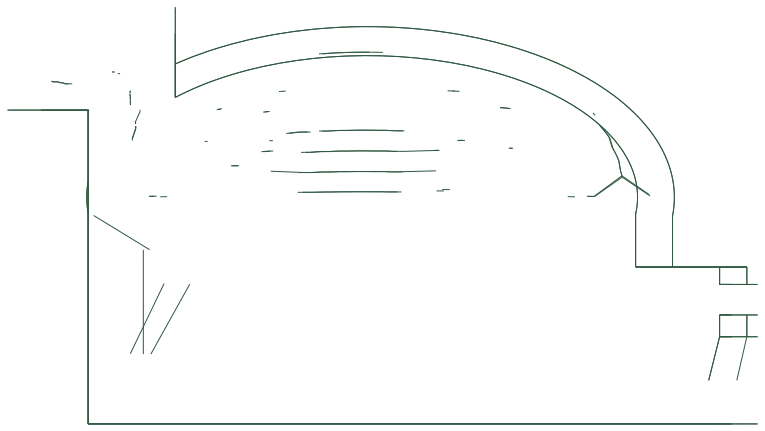
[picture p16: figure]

Overall: 86.04 x 47.80 mm

TOP X-Y

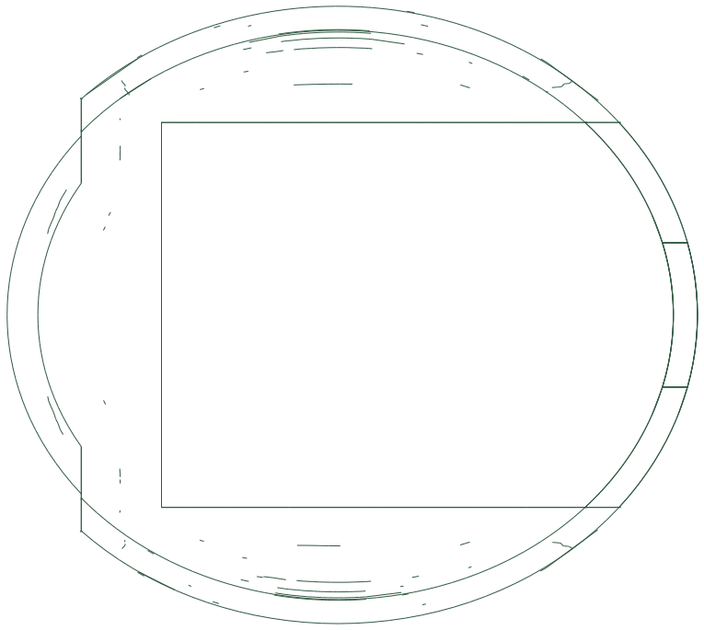
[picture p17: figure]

Overall: 86.04 x 77.20 mm

FRONT Y-Z

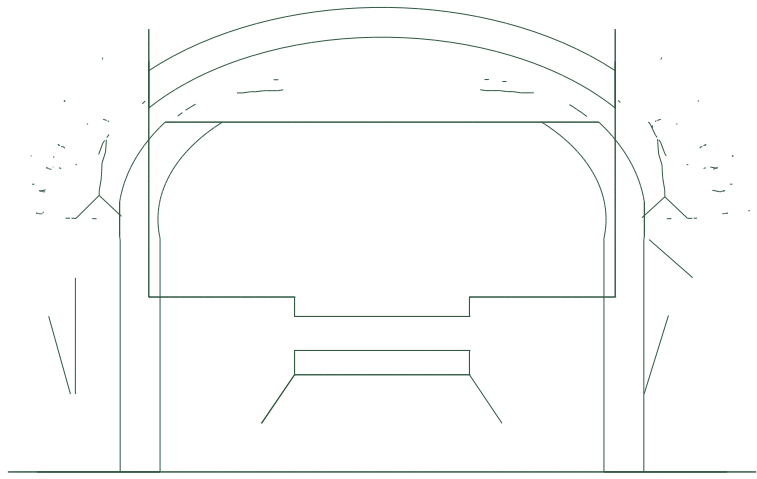
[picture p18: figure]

Overall: 77.20 x 47.80 mm

Assembly-frame extents X/Y/Z: 86.04 / 77.2 / 47.8 mm
Material volume: 23445.0 mm3 | PLA solid-equivalent: 29.07 g (slicer mass will be lower)

One-piece egg shell with a chest grille, neck slot and tail opening, open under the hips. Four M3 through the flanks into chassis bosses. Use STEP for exact geometry. Clearance, fastening, interference and physical fit require prototype verification. Rights: root LICENSE.

# MICRO CAT Rev 1 / tail_cover

link: trunk | millimetres | original design, prototype reference, not production released

SIDE X-Z

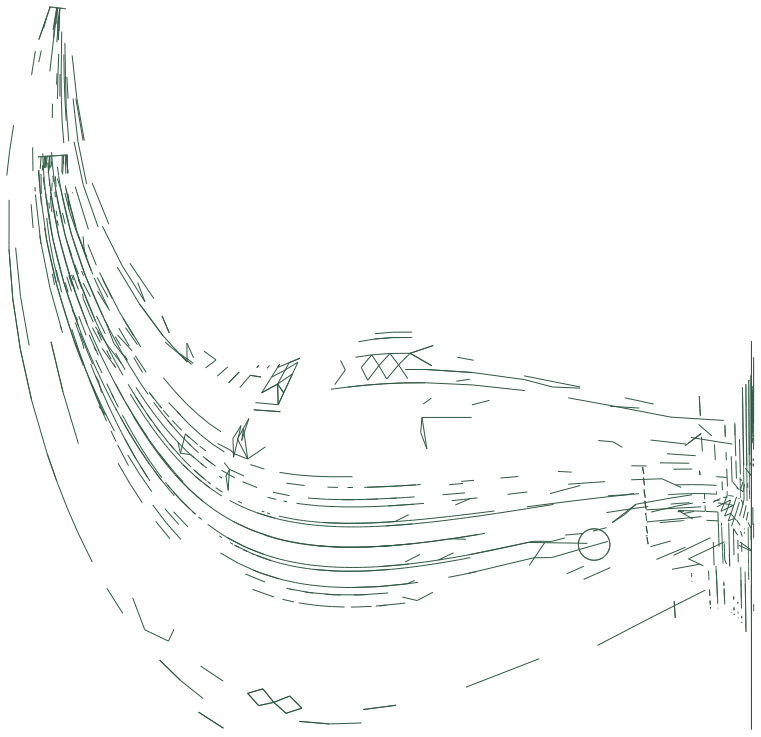
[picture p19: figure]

Overall: 81.06 x 81.59 mm

TOP X-Y

Overall: 81.06 x 66.38 mm

FRONT Y-Z

Overall: 66.38 x 81.59 mm

Assembly-frame extents X/Y/Z: 81.06 / 66.38 / 81.59 mm
Material volume: 34323.4 mm3 | PLA solid-equivalent: 42.56 g (slicer mass will be lower)

Tail: curls up behind the body and doubles as the battery cover. Slides over the tray and takes two M3 into it.
Use STEP for exact geometry. Clearance, fastening, interference and physical fit require prototype verification. Rights: root LICENSE.

# MICRO CAT Rev 1 / neck_link

link: neck | millimetres | original design, prototype reference, not production released

SIDE X-Z

Overall: 24.80 x 71.70 mm

TOP X-Y

Overall: 24.80 x 31.40 mm

FRONT Y-Z

Overall: 31.40 x 71.70 mm

Assembly-frame extents X/Y/Z: 24.8 / 31.4 / 71.7 mm
Material volume: 12901.6 mm3 | PLA solid-equivalent: 16.0 g (slicer mass will be lower)

Neck tube around the stacked neck-pitch and head-pitch servos, open on the horn side. Print on the closed face.
Use STEP for exact geometry. Clearance, fastening, interference and physical fit require prototype verification. Rights: root LICENSE.

# MICRO CAT Rev 1 / neck_sleeve

link: neck | millimetres | original design, prototype reference, not production released

SIDE X-Z

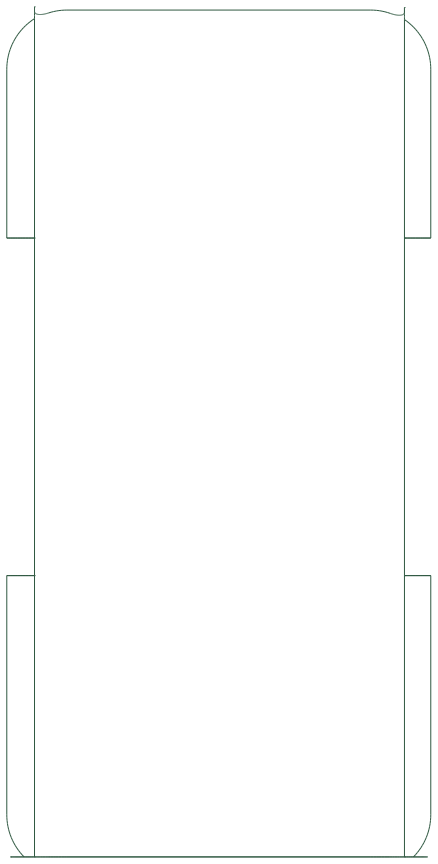
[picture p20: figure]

Overall: 31.60 x 60.44 mm

TOP X-Y

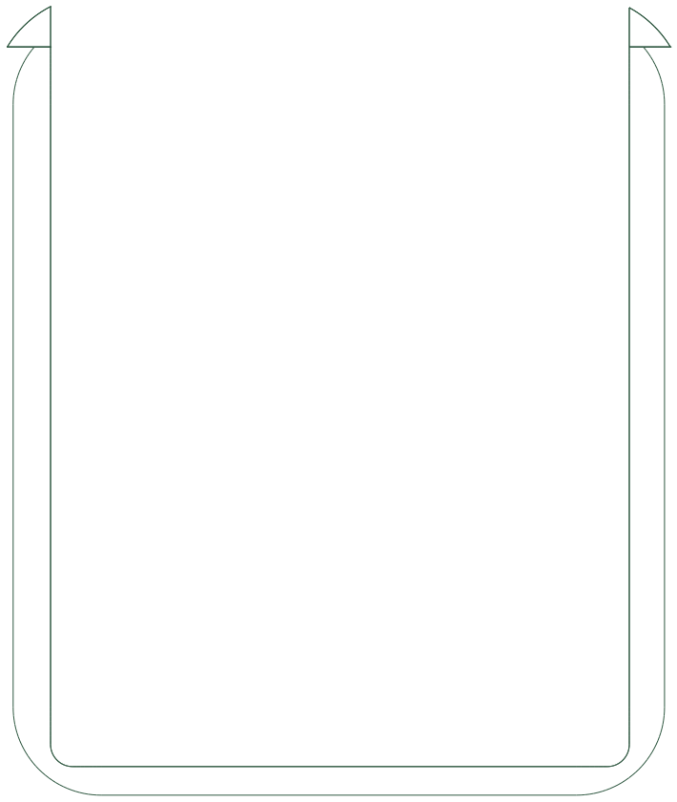
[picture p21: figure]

Overall: 31.60 x 36.84 mm

FRONT Y-Z

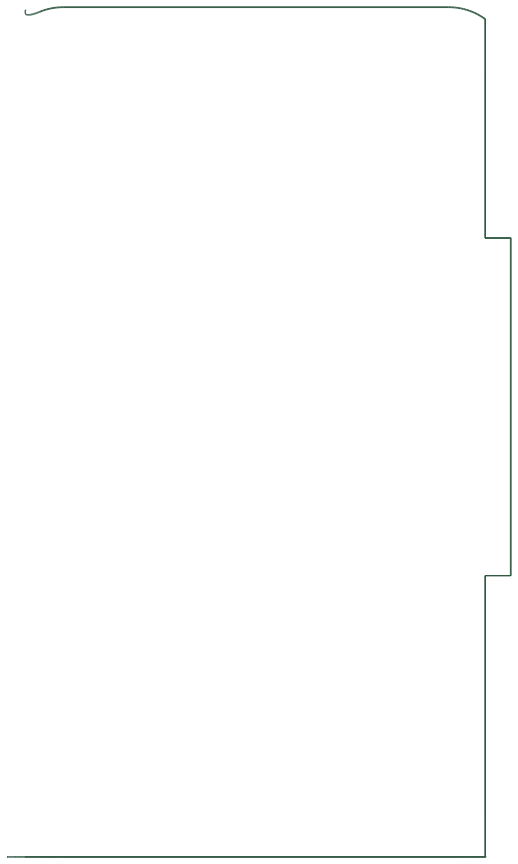
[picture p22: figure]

Overall: 36.84 x 60.44 mm

Assembly-frame extents X/Y/Z: 31.6 / 36.84 / 60.44 mm
Material volume: 13852.3 mm3 | PLA solid-equivalent: 17.18 g (slicer mass will be lower)

Neck cover: rounded shell over the neck column, open on the horn side; pitches with the neck.
Use STEP for exact geometry. Clearance, fastening, interference and physical fit require prototype verification. Rights: root LICENSE.

# MICRO CAT Rev 1 / head_base

link: head_base | millimetres | original design, prototype reference, not production released

SIDE X-Z

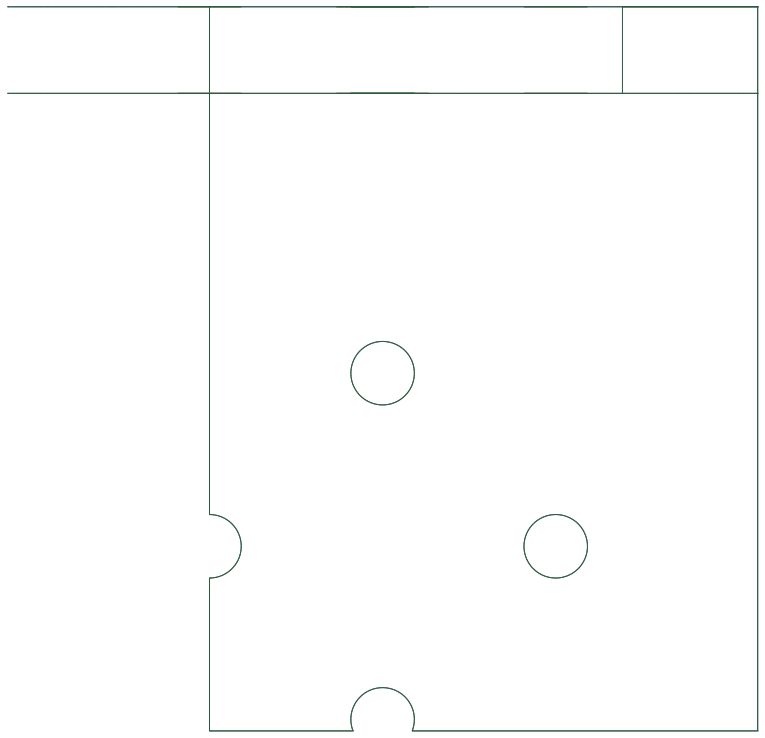
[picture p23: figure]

Overall: 26.00 x 25.10 mm

TOP X-Y

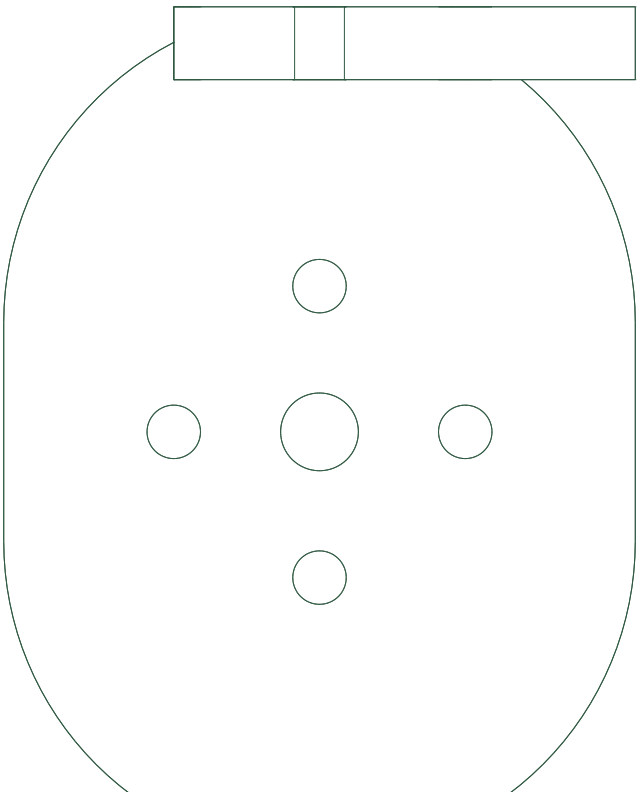
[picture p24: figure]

Overall: 26.00 x 35.00 mm

FRONT Y-Z

Overall: 35.00 x 25.10 mm

Assembly-frame extents X/Y/Z: 26.0 / 35.0 / 25.1 mm
Material volume: 3523.0 mm3 | PLA solid-equivalent: 4.37 g (slicer mass will be lower)

Head base: head-pitch horn plate joined to the head-yaw horn plate. The only part that stays still while the head yaws.
Use STEP for exact geometry. Clearance, fastening, interference and physical fit require prototype verification. Rights: root LICENSE.

# MICRO CAT Rev 1 / head_yoke

link: head_yoke | millimetres | original design, prototype reference, not production released

SIDE X-Z

Overall: 31.30 x 32.40 mm

TOP X-Y

Overall: 31.30 x 37.80 mm

FRONT Y-Z

Overall: 37.80 x 32.40 mm

Assembly-frame extents X/Y/Z: 31.3 / 37.8 / 32.4 mm
Material volume: 12429.4 mm3 | PLA solid-equivalent: 15.41 g (slicer mass will be lower)

Yoke: box around the head-yaw servo with two ribs out to the head-roll horn plate.
Use STEP for exact geometry. Clearance, fastening, interference and physical fit require prototype verification. Rights: root LICENSE.

# MICRO CAT Rev 1 / head_frame

link: head | millimetres | original design, prototype reference, not production released

SIDE X-Z

Overall: 84.20 x 41.70 mm

TOP X-Y

Overall: 84.20 x 61.90 mm

FRONT Y-Z

Overall: 61.90 x 41.70 mm

Assembly-frame extents X/Y/Z: 84.2 / 61.9 / 41.7 mm
Material volume: 20253.1 mm3 | PLA solid-equivalent: 25.11 g (slicer mass will be lower)

Head frame: one shell with a deck over the yoke, the head-roll and jaw servo bays, a forward beam, the camera wall and three skull bosses. Use STEP for exact geometry. Clearance, fastening, interference and physical fit require prototype verification. Rights: root LICENSE.

# MICRO CAT Rev 1 / skull

link: head | millimetres | original design, prototype reference, not production released

SIDE X-Z

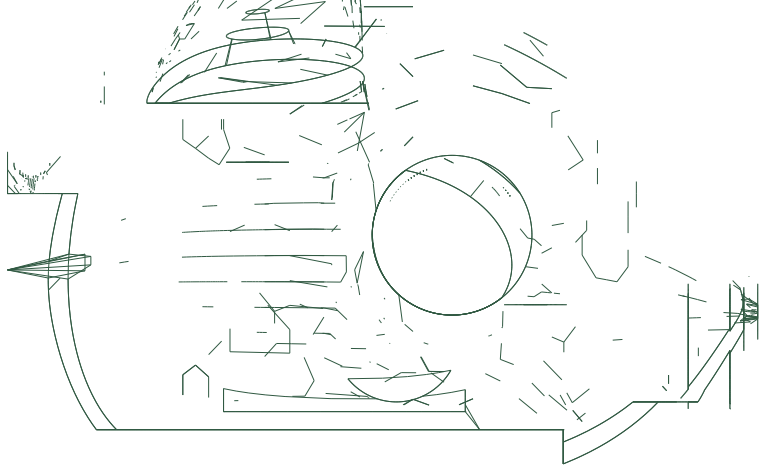
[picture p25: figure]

Overall: 108.00 x 85.93 mm

TOP X-Y

Overall: 108.00 x 112.00 mm

FRONT Y-Z

Overall: 112.00 x 85.93 mm

Assembly-frame extents X/Y/Z: 108.0 / 112.0 / 85.93 mm
Material volume: 69762.2 mm3 | PLA solid-equivalent: 86.51 g (slicer mass will be lower)

Head: one-piece round cat cranium with a short muzzle, solid ears and a nose lens hood. Three M3 down into the head frame; eyes, ear insides and nose are painted, not parts.
Use STEP for exact geometry. Clearance, fastening, interference and physical fit require prototype verification. Rights: root LICENSE.

# MICRO CAT Rev 1 / jaw_chin

link: jaw | millimetres | original design, prototype reference, not production released

SIDE X-Z

Overall: 58.00 x 32.00 mm

TOP X-Y

Overall: 58.00 x 39.97 mm

FRONT Y-Z

Overall: 39.97 x 32.00 mm

Assembly-frame extents X/Y/Z: 58.0 / 39.97 / 32.0 mm
Material volume: 5602.3 mm3 | PLA solid-equivalent: 6.95 g (slicer mass will be lower)

Lower jaw: rounded chin cup on a single arm bolted to the jaw servo horn.
Use STEP for exact geometry. Clearance, fastening, interference and physical fit require prototype verification. Rights: root LICENSE.

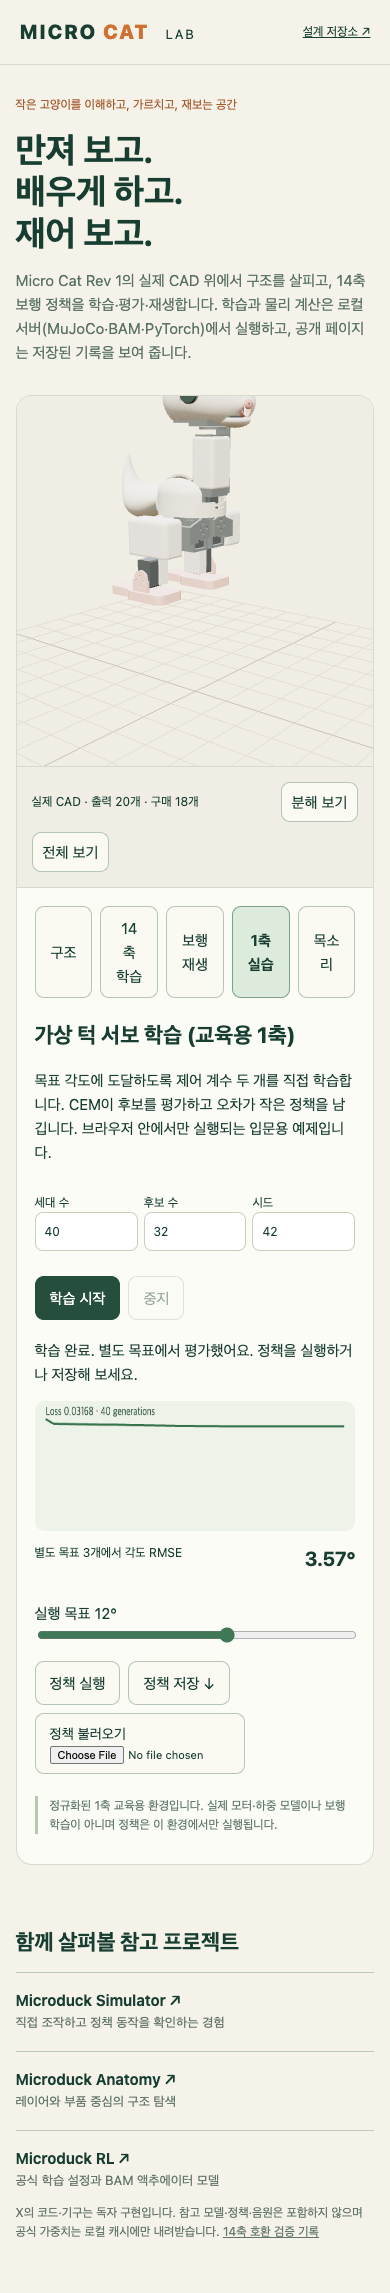
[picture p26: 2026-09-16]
artifacts/lab_mobile.png

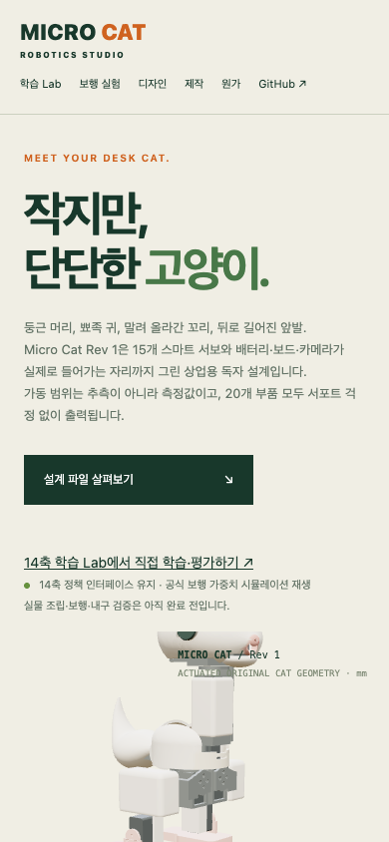
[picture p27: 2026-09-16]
artifacts/web_mobile.png

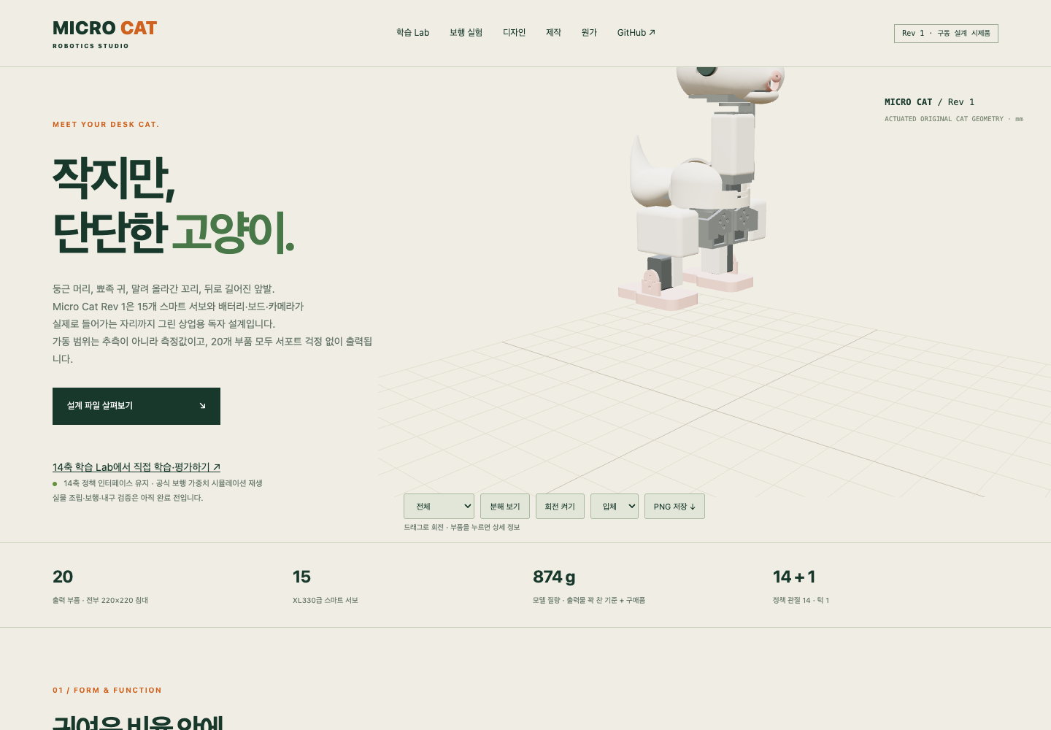
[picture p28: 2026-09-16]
artifacts/web_desktop.png

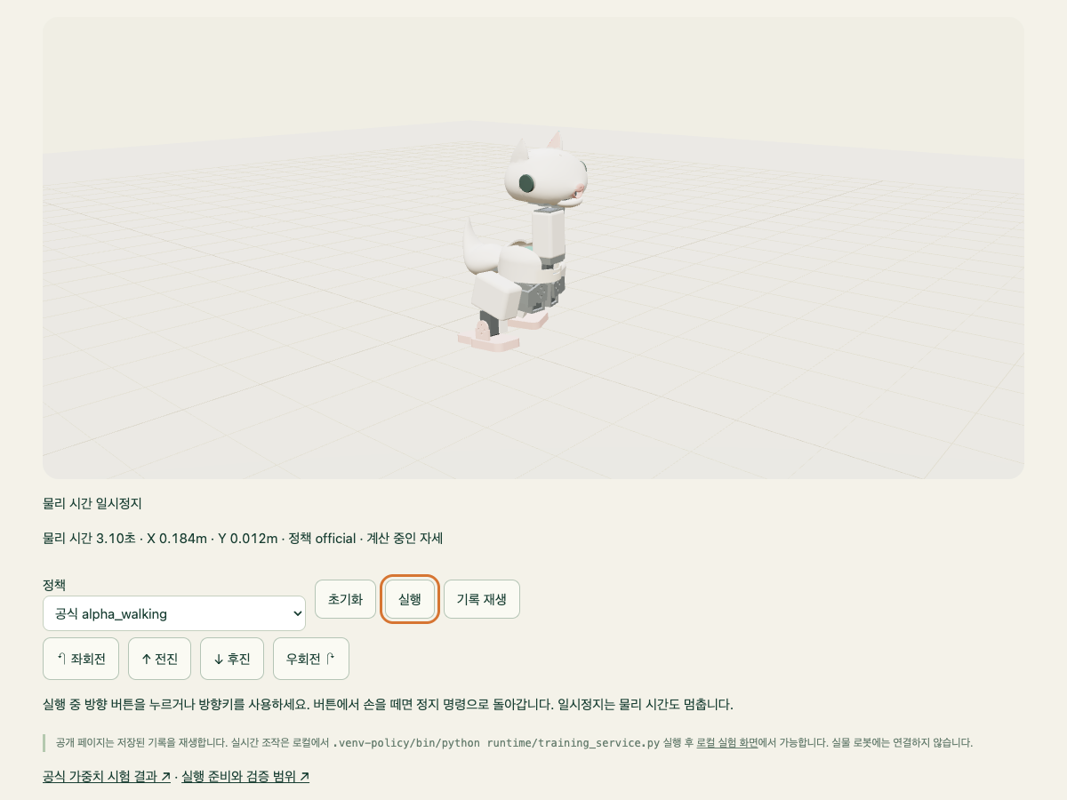
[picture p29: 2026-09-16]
artifacts/simulator_desktop.png

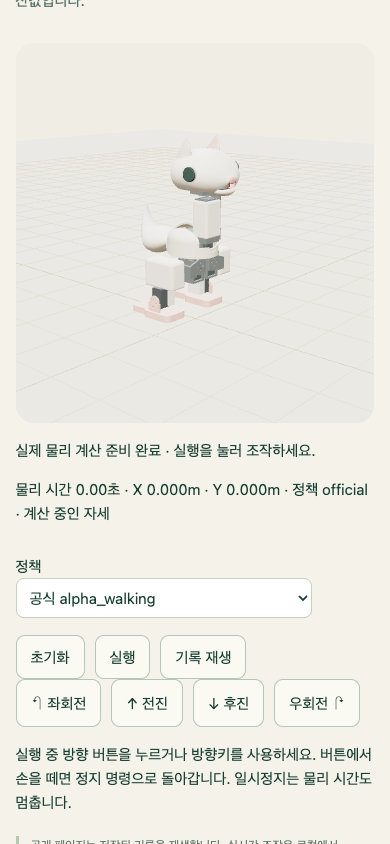
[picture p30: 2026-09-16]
artifacts/simulator_mobile.png

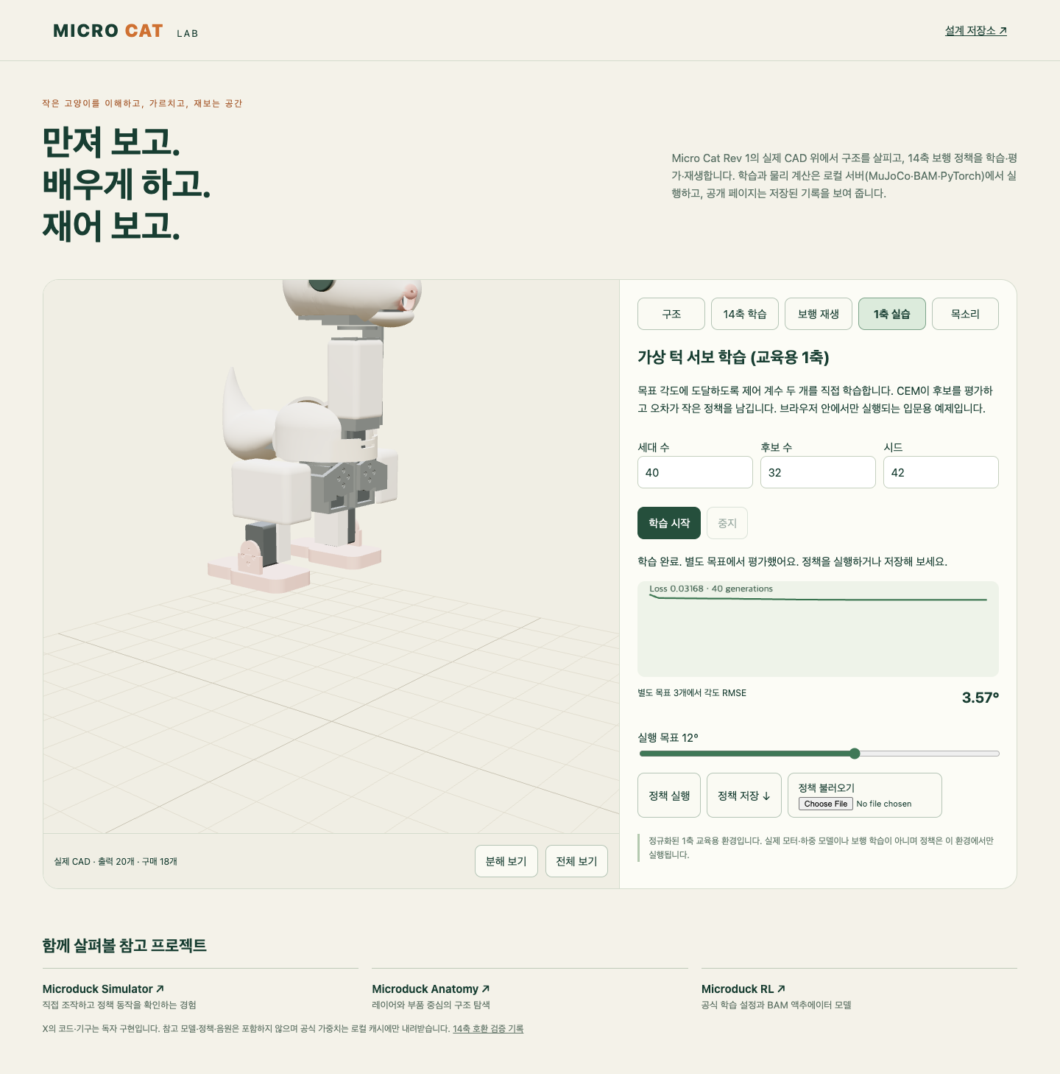
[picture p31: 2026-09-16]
artifacts/lab_desktop.png

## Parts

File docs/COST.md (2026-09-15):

# 원가 가정 (견적이 아님)

기준 시점 2026-09-13. 웹의 계산기는 아래 입력을 기본값으로 쓰며 모두 편집 가능합니다. 세금·배송·관세·금형·개발비·인증·포장·유통·보증·마진은 제외합니다.

| 항목 | 기본값 | 근거 |
|---|---|---|
| 모터 15개 | $27.49 × 15 = $412.35 | XL330-M288-T ROBOTIS 미국 소매가 1개, 수량 할인 미표시 (https://www.robotis.us/dynamixel-xl330-m288-t/) |
| 전장·배터리·카메라·체결 | $110 (가정) | 싱글보드 컴퓨터(50 × 27 mm까지), IMU, 마이크·스피커, TTL 버스 어댑터, 전원 보드, 2S 18650급 배터리, Camera Module 3급, 나사류 |
| 출력·마감·조립 | $45 (가정) | 20개 출력 부품 450 g(꽉 찬 기준; 실제 인필은 더 적음), 조립 인건 |
| 수율 | 95 % (가정) | |
| **계산기 합계** | **≈ $597** | 소매가 모터 기준이므로 Microduck 사전예약가 $399보다 높음 |

결론은 명확합니다: **소매가 XL330 15개만으로 Microduck 판매가를 넘습니다.** 상업화 경로는 (1) 모터 대량 견적, (2) 헤드·턱 등 저부하 축에 저가 서보 혼용 검토(정책 호환은 다리 10축과 목 4축에 한정되므로 턱은 자유), (3) 출력 대신 사출은 수량이 확정된 뒤. 이 저장소는 계산기와 가정을 공개하고 실제 견적을 받은 뒤 값을 바꿉니다.

## Microduck 참고 가격 (공개 정보)

- 조립 완제품 $399 (사전예약, 세금·배송 별도), 게임패드 포함, 배터리 1개 (NP-F550, 2600 mAh, 약 1시간). 출처: Pollen Robotics 프레스킷·스토어, Engadget 2026-08-27.
- 액세서리 팩 $39, 충전 팩 $39, 개발 팩 $119.
- 하드웨어 설계 파일은 비공개(소프트웨어만 오픈소스). Micro Cat는 독자 설계로 이 제약을 받지 않습니다.

## 설계로 낮추는 항목

- 공용 M2/M3 두 규격, 혼·아이들러 판 8볼트로 서보 교체 표준화.
- 배터리는 2S 18650급 팩으로, 셀과 충전기를 어디서나 구할 수 있고 꼬리 커버만 빼면 교체됩니다.
- 외장 7개(몸통·목 커버·두개골·아래턱·꼬리·발 2)와 프레임 13개로 분리해 외장만 사출 전환 가능.
- 발 바닥은 평평하고 속이 비어 TPU 패드만 교체.
- 모든 부품이 220 × 220 침대에 들어가고 브래킷은 서포트가 필요 없어 출력 시간과 후처리가 줄어듭니다(`artifacts/printability.json`).

실측(슬라이서 질량, 출력 시간, 조립 분, 1차 수율)은 실물 제작 후 이 파일에 추가합니다.

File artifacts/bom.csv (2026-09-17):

item | quantity | kind | link | basis | mass_g | status | file
left_yaw2roll | 1 | printed | left_yaw2roll | PLA solid-equivalent volume; infill and material not frozen | 17.03 | Rev 1 digital design | models/step/left_yaw2roll.step
left_hip | 1 | printed | left_hip | PLA solid-equivalent volume; infill and material not frozen | 6.28 | Rev 1 digital design | models/step/left_hip.step
left_upper_leg | 1 | printed | left_upper_leg | PLA solid-equivalent volume; infill and material not frozen | 23.06 | Rev 1 digital design | models/step/left_upper_leg.step
left_lower_leg | 1 | printed | left_lower_leg | PLA solid-equivalent volume; infill and material not frozen | 8.55 | Rev 1 digital design | models/step/left_lower_leg.step
left_foot | 1 | printed | left_foot | PLA solid-equivalent volume; infill and material not frozen | 38.72 | Rev 1 digital design | models/step/left_foot.step
right_yaw2roll | 1 | printed | right_yaw2roll | PLA solid-equivalent volume; infill and material not frozen | 17.03 | Rev 1 digital design | models/step/right_yaw2roll.step
right_hip | 1 | printed | right_hip | PLA solid-equivalent volume; infill and material not frozen | 6.28 | Rev 1 digital design | models/step/right_hip.step
right_upper_leg | 1 | printed | right_upper_leg | PLA solid-equivalent volume; infill and material not frozen | 23.06 | Rev 1 digital design | models/step/right_upper_leg.step
right_lower_leg | 1 | printed | right_lower_leg | PLA solid-equivalent volume; infill and material not frozen | 8.55 | Rev 1 digital design | models/step/right_lower_leg.step
right_foot | 1 | printed | right_foot | PLA solid-equivalent volume; infill and material not frozen | 38.72 | Rev 1 digital design | models/step/right_foot.step
chassis | 1 | printed | trunk | PLA solid-equivalent volume; infill and material not frozen | 44.21 | Rev 1 digital design | models/step/chassis.step
torso_shell | 1 | printed | trunk | PLA solid-equivalent volume; infill and material not frozen | 29.07 | Rev 1 digital design | models/step/torso_shell.step
tail_cover | 1 | printed | trunk | PLA solid-equivalent volume; infill and material not frozen | 42.56 | Rev 1 digital design | models/step/tail_cover.step
neck_link | 1 | printed | neck | PLA solid-equivalent volume; infill and material not frozen | 16.0 | Rev 1 digital design | models/step/neck_link.step
neck_sleeve | 1 | printed | neck | PLA solid-equivalent volume; infill and material not frozen | 17.18 | Rev 1 digital design | models/step/neck_sleeve.step
head_base | 1 | printed | head_base | PLA solid-equivalent volume; infill and material not frozen | 4.37 | Rev 1 digital design | models/step/head_base.step
head_yoke | 1 | printed | head_yoke | PLA solid-equivalent volume; infill and material not frozen | 15.41 | Rev 1 digital design | models/step/head_yoke.step
head_frame | 1 | printed | head | PLA solid-equivalent volume; infill and material not frozen | 25.11 | Rev 1 digital design | models/step/head_frame.step
skull | 1 | printed | head | PLA solid-equivalent volume; infill and material not frozen | 86.51 | Rev 1 digital design | models/step/skull.step
jaw_chin | 1 | printed | jaw | PLA solid-equivalent volume; infill and material not frozen | 6.95 | Rev 1 digital design | models/step/jaw_chin.step
servo_left_hip_yaw | 1 | actuator | trunk | XL330-class smart servo envelope; confirm the case hole pattern before ordering | 18.0 | purchased envelope; supplier quote pending | models/purchased/servo_left_hip_yaw.stl
servo_left_hip_roll | 1 | actuator | left_yaw2roll | XL330-class smart servo envelope; confirm the case hole pattern before ordering | 18.0 | purchased envelope; supplier quote pending | models/purchased/servo_left_hip_roll.stl
servo_left_hip_pitch | 1 | actuator | left_upper_leg | XL330-class smart servo envelope; confirm the case hole pattern before ordering | 18.0 | purchased envelope; supplier quote pending | models/purchased/servo_left_hip_pitch.stl
servo_left_knee | 1 | actuator | left_upper_leg | XL330-class smart servo envelope; confirm the case hole pattern before ordering | 18.0 | purchased envelope; supplier quote pending | models/purchased/servo_left_knee.stl
servo_left_ankle | 1 | actuator | left_lower_leg | XL330-class smart servo envelope; confirm the case hole pattern before ordering | 18.0 | purchased envelope; supplier quote pending | models/purchased/servo_left_ankle.stl
servo_right_hip_yaw | 1 | actuator | trunk | XL330-class smart servo envelope; confirm the case hole pattern before ordering | 18.0 | purchased envelope; supplier quote pending | models/purchased/servo_right_hip_yaw.stl
servo_right_hip_roll | 1 | actuator | right_yaw2roll | XL330-class smart servo envelope; confirm the case hole pattern before ordering | 18.0 | purchased envelope; supplier quote pending | models/purchased/servo_right_hip_roll.stl
servo_right_hip_pitch | 1 | actuator | right_upper_leg | XL330-class smart servo envelope; confirm the case hole pattern before ordering | 18.0 | purchased envelope; supplier quote pending | models/purchased/servo_right_hip_pitch.stl
servo_right_knee | 1 | actuator | right_upper_leg | XL330-class smart servo envelope; confirm the case hole pattern before ordering | 18.0 | purchased envelope; supplier quote pending | models/purchased/servo_right_knee.stl
servo_right_ankle | 1 | actuator | right_lower_leg | XL330-class smart servo envelope; confirm the case hole pattern before ordering | 18.0 | purchased envelope; supplier quote pending | models/purchased/servo_right_ankle.stl
servo_neck_pitch | 1 | actuator | neck | XL330-class smart servo envelope; confirm the case hole pattern before ordering | 18.0 | purchased envelope; supplier quote pending | models/purchased/servo_neck_pitch.stl
servo_head_pitch | 1 | actuator | neck | XL330-class smart servo envelope; confirm the case hole pattern before ordering | 18.0 | purchased envelope; supplier quote pending | models/purchased/servo_head_pitch.stl
servo_head_yaw | 1 | actuator | head_yoke | XL330-class smart servo envelope; confirm the case hole pattern before ordering | 18.0 | purchased envelope; supplier quote pending | models/purchased/servo_head_yaw.stl
servo_head_roll | 1 | actuator | head | XL330-class smart servo envelope; confirm the case hole pattern before ordering | 18.0 | purchased envelope; supplier quote pending | models/purchased/servo_head_roll.stl
servo_jaw | 1 | actuator | head | XL330-class smart servo envelope; confirm the case hole pattern before ordering | 18.0 | purchased envelope; supplier quote pending | models/purchased/servo_jaw.stl
battery_pack | 1 | battery | trunk | Removable 2S 18650 pack, 65 x 37 x 19 mm class, 7.4 V ~3000 mAh; slides out with the tail cover | 95 | purchased envelope; supplier quote pending | models/purchased/battery_pack.stl
compute_board | 1 | electronics | trunk | Single-board computer, compact bay: 26.5 x 47 mm. Boards: board to be selected. Connectors, camera FFC, wiring and cooling are not in this envelope | 30 | purchased envelope; supplier quote pending | models/purchased/compute_board.stl
camera_module_3 | 1 | camera | head | Raspberry Pi Camera Module 3 Standard class, 25 x 24 mm board; the nose bore is a 14 mm funnel, so the usable field of view is about 60 deg, narrower than the module rating | 4 | purchased envelope; supplier quote pending | models/purchased/camera_module_3.stl
# measured joint travel (deg) | min | max
left_hip_yaw | -29.8 | 29.8
left_hip_roll | -22.9 | 20.1
left_hip_pitch | -90.0 | 51.6
left_knee | -90.0 | 63.0
left_ankle | -31.5 | 31.5
right_hip_yaw | -29.8 | 29.8
right_hip_roll | -20.1 | 22.9
right_hip_pitch | -51.6 | 90.0
right_knee | -63.0 | 90.0
right_ankle | -31.5 | 31.5
neck_pitch | -11.5 | 22.9
head_pitch | -48.7 | 54.4
head_yaw | -114.6 | 114.6
head_roll | -5.7 | 8.6
jaw | 0.0 | 5.7
M2 x 6 screws, servo horn/idler to clevis plates | 120 | hardware |  | Four per horn and four per idler pattern; confirm thread engagement in the printed plate |  | Not procurement-ready
M2 case screws or keeper clips, servo body retention | 30 | hardware |  | Depends on the confirmed XL330 case hole pattern |  | Not procurement-ready
M3 x 8 plastic thread-forming screws (shell to chassis, skull to rail, eyes, tail cover) | 12 | hardware |  | Pilot Ø2.6 in printed bosses; coupon test first |  | Not procurement-ready
16 x 22 x 4 mm bearing (optional hip yaw support) | 2 | hardware |  | Optional plain/rolling bearing under each hip yaw plate |  | Design option
2S 18650 battery pack, 65 x 37 x 19 mm class | 1 | hardware |  | Slides out with the tail cover; cells and chargers are commodity items |  | Not procurement-ready
IMU board, microphone, speaker, wiring, TTL bus adapter, power board | 1 | hardware |  | Not yet placed in CAD; trunk deck volume reserved |  | Architecture decision required
TPU sole pads | 2 | hardware |  | Fill the hollow sole underside; durometer to be chosen |  | Follow-up

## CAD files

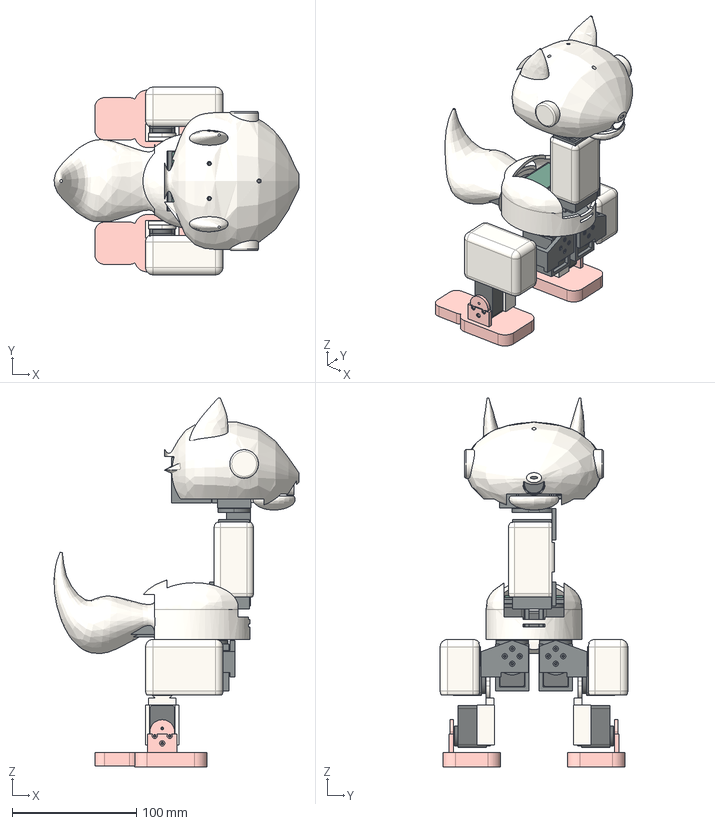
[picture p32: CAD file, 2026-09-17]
models/micro_cat.step
196.7 x 150.8 x 296.5 mm
left_yaw2roll
left_hip
left_upper_leg
left_lower_leg
left_foot
right_yaw2roll
right_hip
right_upper_leg
right_lower_leg
right_foot
chassis
torso_shell
tail_cover
neck_link
neck_sleeve
head_base
head_yoke
head_frame
skull
jaw_chin
servo_left_hip_yaw
servo_left_hip_roll
servo_left_hip_pitch
servo_left_knee
servo_left_ankle
servo_right_hip_yaw
servo_right_hip_roll
servo_right_hip_pitch
servo_right_knee
servo_right_ankle
servo_neck_pitch
servo_head_pitch
servo_head_yaw
servo_head_roll
servo_jaw
battery_pack
compute_board
camera_module_3

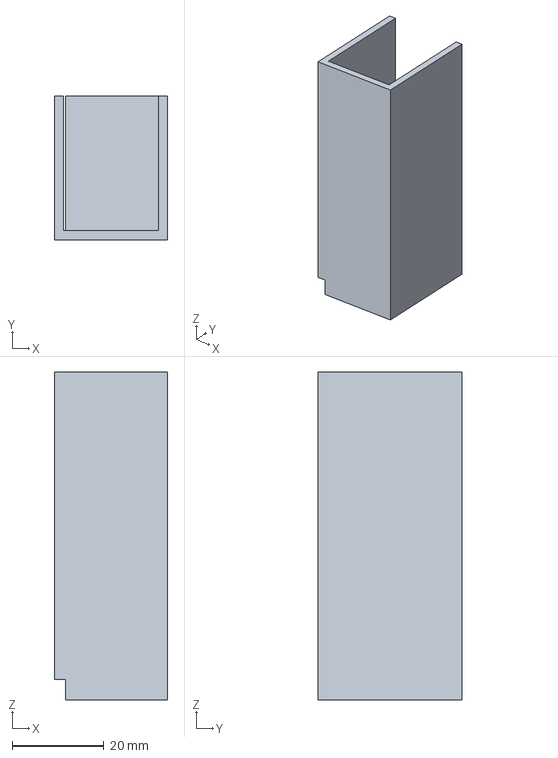
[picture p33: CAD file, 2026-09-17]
models/step/neck_link.step
24.8 x 31.4 x 71.7 mm

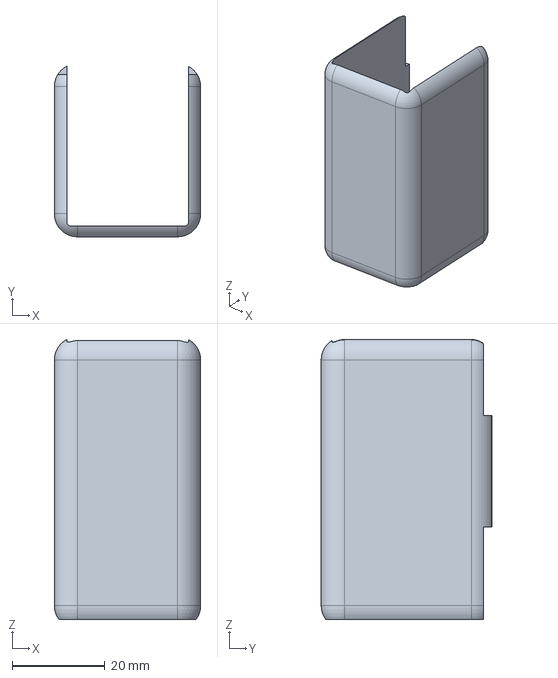
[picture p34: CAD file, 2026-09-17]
models/step/neck_sleeve.step
31.6 x 36.8 x 60.4 mm

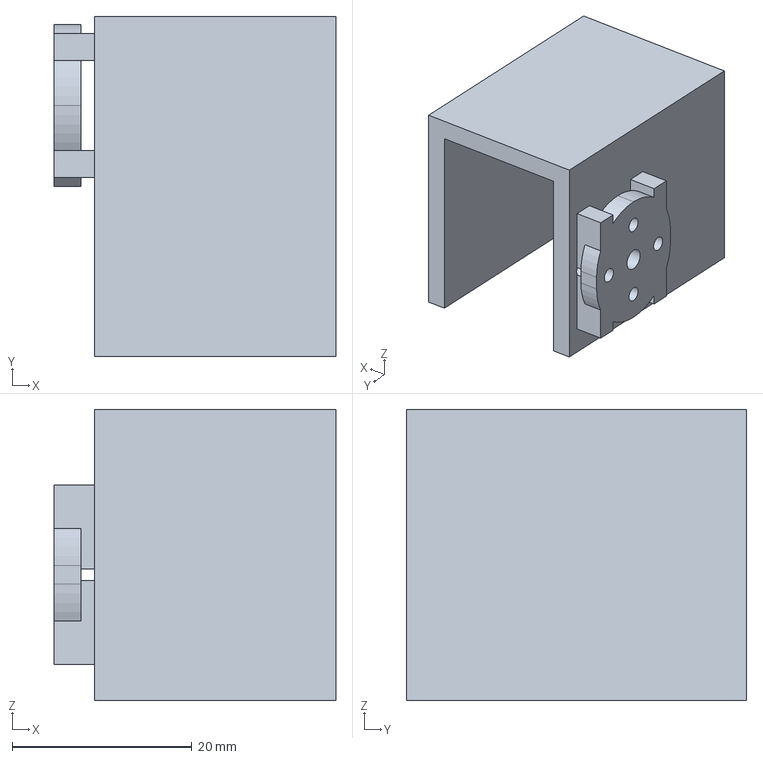
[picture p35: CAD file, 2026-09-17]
models/step/head_yoke.step
31.3 x 37.8 x 32.4 mm

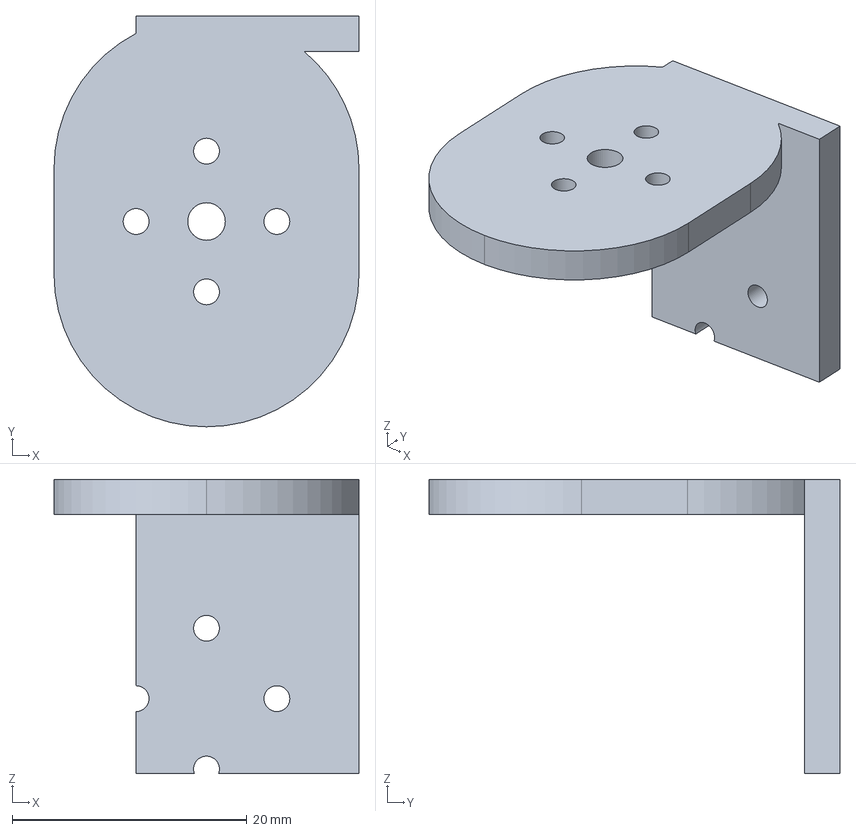
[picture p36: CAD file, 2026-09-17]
models/step/head_base.step
26.0 x 35.0 x 25.1 mm

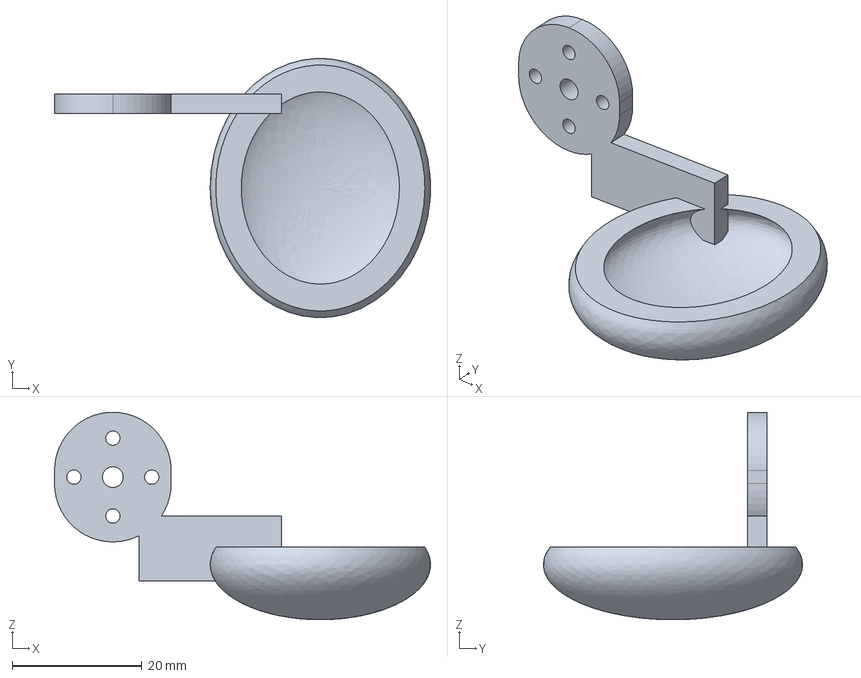
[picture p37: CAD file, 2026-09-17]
models/step/jaw_chin.step
58.0 x 40.0 x 32.0 mm

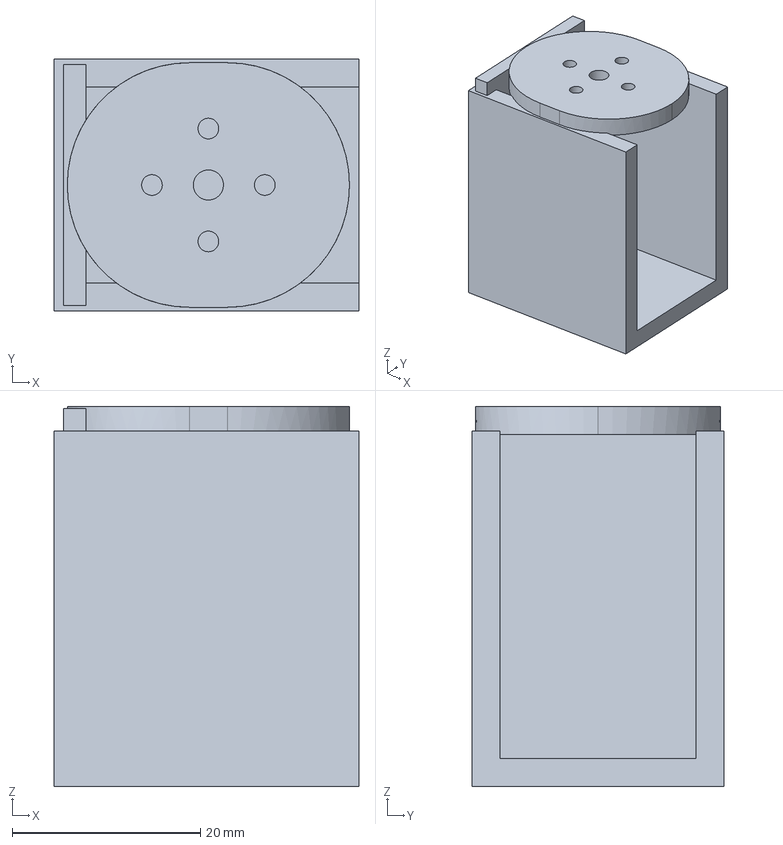
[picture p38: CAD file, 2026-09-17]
models/step/right_yaw2roll.step
32.4 x 26.8 x 40.4 mm

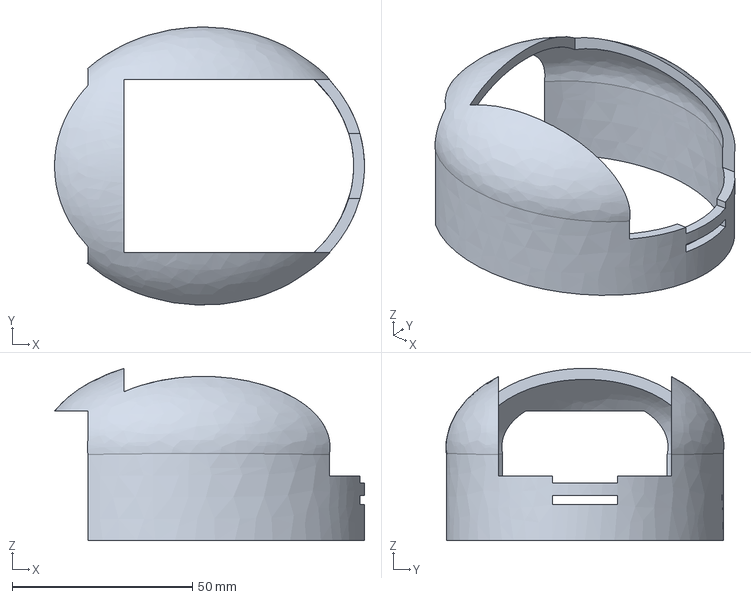
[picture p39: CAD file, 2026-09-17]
models/step/torso_shell.step
86.0 x 77.1 x 47.8 mm

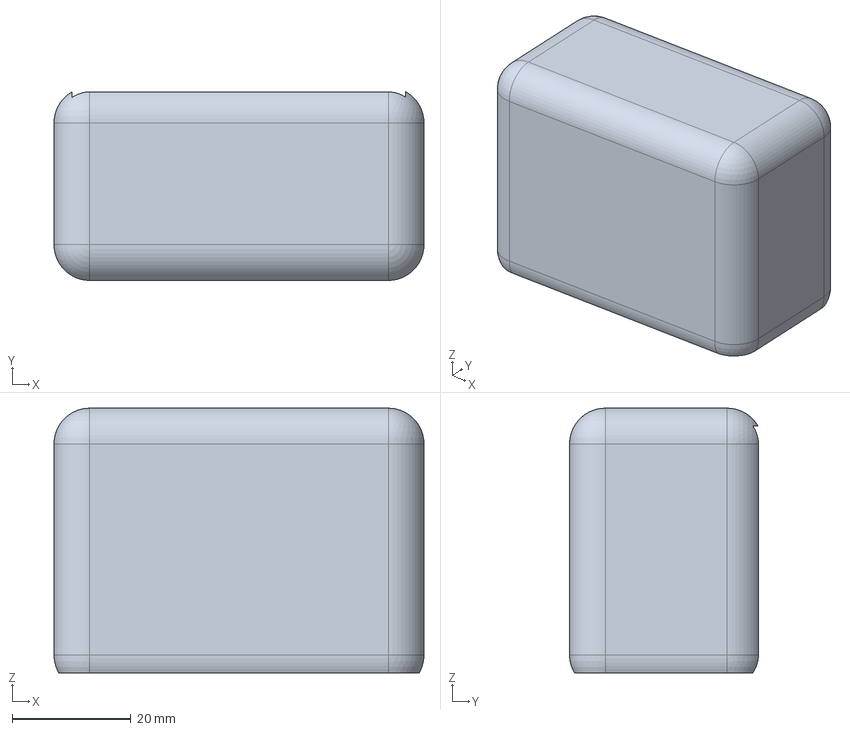
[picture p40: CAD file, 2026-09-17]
models/step/right_upper_leg.step
62.2 x 31.8 x 44.5 mm

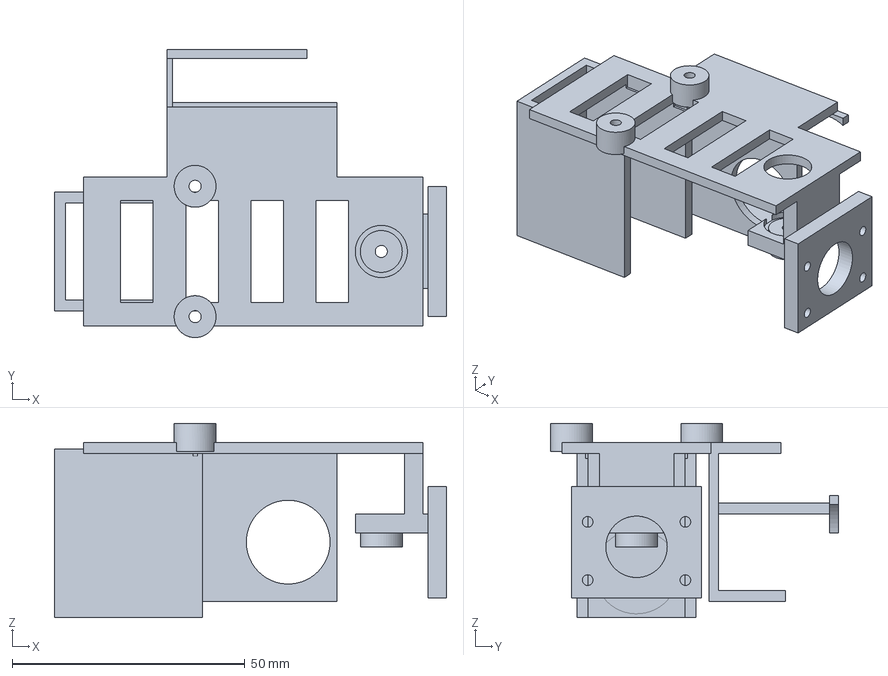
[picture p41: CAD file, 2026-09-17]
models/step/head_frame.step
84.2 x 61.9 x 41.7 mm

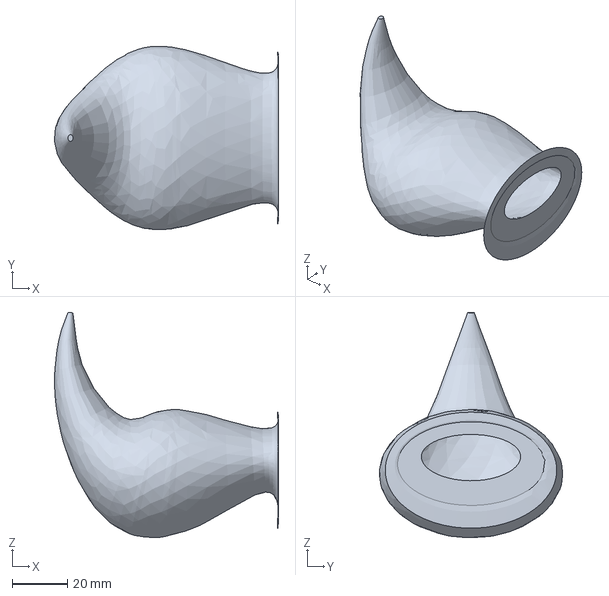
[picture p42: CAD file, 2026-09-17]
models/step/tail_cover.step
81.0 x 66.4 x 81.5 mm

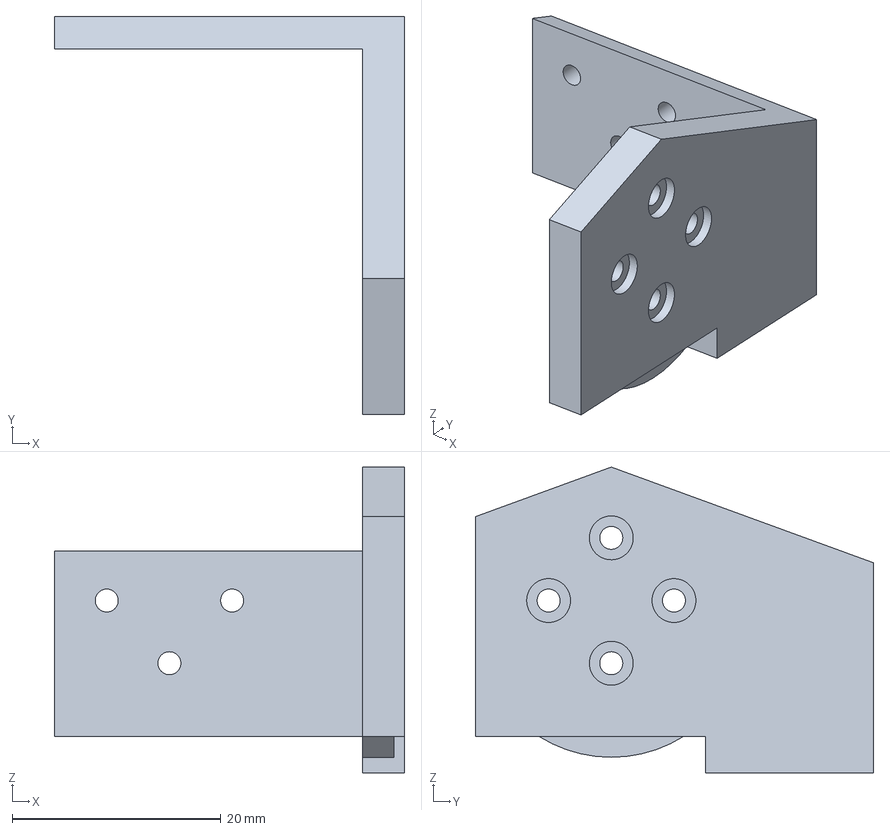
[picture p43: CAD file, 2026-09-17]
models/step/left_hip.step
33.5 x 38.1 x 29.3 mm

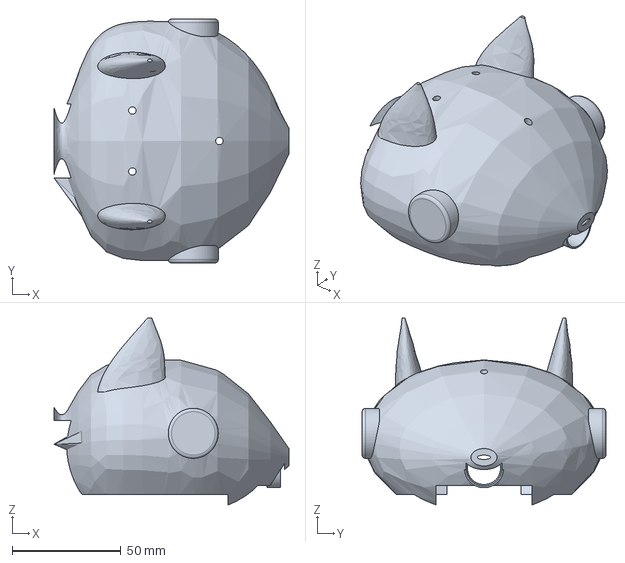
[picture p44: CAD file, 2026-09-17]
models/step/skull.step
108.0 x 112.0 x 85.9 mm

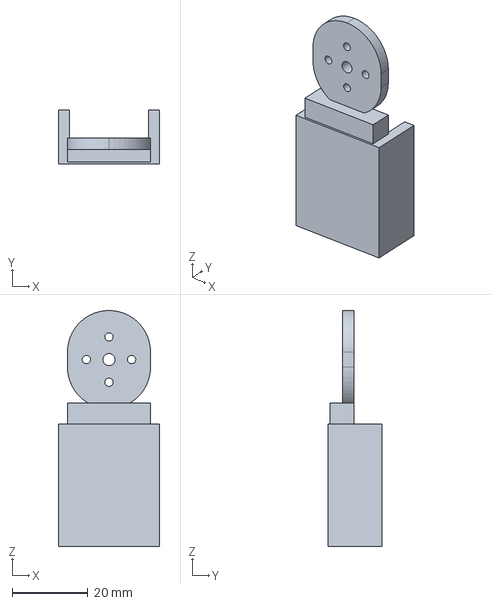
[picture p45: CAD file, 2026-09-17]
models/step/left_lower_leg.step
26.8 x 14.4 x 62.5 mm

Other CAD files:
models/step/left_yaw2roll.step
models/step/right_hip.step
models/step/left_foot.step
models/step/left_upper_leg.step
models/chassis.stl
models/head_base.stl
models/head_frame.stl
models/head_yoke.stl
models/jaw_chin.stl
models/left_foot.stl
models/left_hip.stl
models/left_lower_leg.stl
models/left_upper_leg.stl
models/left_yaw2roll.stl
models/neck_link.stl
models/neck_sleeve.stl
models/print/chassis.stl
models/print/head_base.stl
models/print/head_frame.stl
models/print/head_yoke.stl
models/print/jaw_chin.stl
models/print/left_foot.stl
models/print/left_hip.stl
models/print/left_lower_leg.stl
models/print/left_upper_leg.stl
models/print/left_yaw2roll.stl
models/print/neck_link.stl
models/print/neck_sleeve.stl
models/print/right_foot.stl
models/print/right_hip.stl
models/print/right_lower_leg.stl
models/print/right_upper_leg.stl
models/print/right_yaw2roll.stl
models/print/skull.stl
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

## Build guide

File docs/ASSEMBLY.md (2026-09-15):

# Micro Cat Rev 1 — 조립 순서와 인터페이스

디지털 설계의 조립 의도입니다. 실물 출력 공차·나사 체결·케이블 경로는 아직 확인 전입니다. 좌표는 조립 기준 프레임(mm, X 앞, Y 왼쪽, Z 위, 바닥 Z=0, 몸통 기준 프레임 Z=120). `models/print/`는 출력 방향으로 눕힌 STL, `models/step/`와 `models/*.stl`은 조립 좌표입니다. 모든 부품은 다리를 곧게 편 **설계 자세**로 그려져 있습니다.

## 공통 규칙

- **서보 고정**: 서보 몸체는 한쪽 링크의 U자 채널에 0.4 mm 여유로 들어가고, 이웃 링크의 혼 판이 출력 혼에 M2 4개로 붙습니다. 판 두께 3 mm, 혼 면과 판 사이 0.5 mm, 볼트는 Ø12 원 위 4×Ø2.2입니다. 서보 몸체 자체는 채널 벽과 이웃 판이 잡습니다. 케이스 측면 홀은 아직 모델에 없으므로, 실물 서보의 홀 패턴을 확인해 몸체 고정 나사나 키퍼를 추가해야 합니다(`engineering/actuator_interface.json`).
- **M3 체결**: Ø2.6 파일럿(플라스틱용 태핑 나사)과 Ø3.4 관통. `models/coupons/`의 시편으로 프린터 보정 후 출력하세요.
- **출력**: 부품마다 방향이 고정되어 있습니다(`artifacts/printability.json`). 브래킷류는 면 하나를 침대에 붙이면 벽이 전부 수직이라 서포트가 필요 없습니다. 아래턱과 꼬리 커버는 곡면이라 브림을 권합니다. 허벅지·목 커버·꼬리는 침대 접촉 면적이 0 mm²라 브림 또는 서포트가 필요합니다(`artifacts/printability.json`).

## 1. 다리 (좌우 대칭, 왼쪽 기준)

1. **요·롤 브래킷** `left_yaw2roll` — 고관절 요 혼 판(z 112…115) 아래에 고관절 롤 서보용 U자 채널(벽 y 4.7…7.1 / 27.9…30.3, 바닥 캡 z 75.2…78). 롤 서보를 아래에서 넣고, 요 서보 혼에 M2 4개로 붙입니다. 판 면을 침대에 놓고 출력.
2. **고관절 브래킷** `left_hip` — 롤 혼 판(x 22.5…25.5)과 피치 혼 판(y 39.5…42.5)을 리브 하나로 이은 코너. 윗면은 평면이 아니라 **롤 축을 중심으로 ±0.35 rad 회전시킨 섀시 바닥면의 하한 포락선**으로 깎여 있습니다. 평면으로 깎으면 바깥 리브가 몸통 스커트에 걸려 롤이 +5.7°에서 멈춥니다.
3. **허벅지** `left_upper_leg` — 고관절 피치 서보와 무릎 서보를 나란히 감싸는 쉘. 안쪽(−Y)과 아래가 열려 있어 서보를 옆에서 넣고, 무릎을 접을 때 종아리가 들어올 공간이 됩니다. 바깥 면을 침대에 놓으면 공동이 위로 열려 서포트가 없습니다.
4. **종아리** `left_lower_leg` — 무릎 혼 판(y 35.5…38.5)에서 내려와 발목 서보를 감싸는 채널. 발이 기울 수 있도록 z 31 아래는 비어 있습니다.
5. **앞발** `left_foot` — 발목 혼 판이 바닥판까지 이어집니다. 바닥판은 기준 로봇의 발보다 **뒤로 16 mm 더 깁니다**(x −70…4). 뒤로 넘어지는 방향이 이 로봇의 가장 약한 정적 축이고, 뒤쪽 지지 거리가 그 각도를 결정하기 때문입니다. 윗면·아랫면 모두 평면, 옆면만 라운드이며 속이 비어 TPU 패드를 넣을 수 있습니다.

## 2. 몸통

1. **섀시** `chassis` — 타원 바닥판(z 118…121)에 고관절 요 서보 박스 2개, 목 피치 혼 판(x 6…39, y 14.5…17.5, z 145.3…167.4), 전장 데크(z 147…149.5, 보드 최대 50 × 27 mm), 배터리 트레이(x −92…−25), 쉘 보스 4개. 요 서보는 바닥판 구멍으로 넣어 요·롤 브래킷의 혼 판이 잡습니다. 바닥을 침대에 놓고 출력하며, 서보 박스의 천장은 약 21 mm 브리지입니다.
2. **몸통 쉘** `torso_shell` — 아래는 곧은 타원 통(z 121…142), 위는 돔. 앞 가슴 그릴, 목 슬롯, 뒤 배터리 개구가 있고 아래는 열려 있습니다. 옆면 구멍 4개(x −26 / 20, z 132)로 바깥에서 M3를 섀시 보스에 체결합니다. 열린 쪽을 아래로 놓고 출력.
3. **꼬리** `tail_cover` — 중심선 접평면 위에 놓인 단면 7개 로프트로, 뒤로 나갔다가 위로 말려 올라갑니다. 앞쪽 곧은 구간이 배터리 커버입니다. 배터리를 트레이에 넣고 뒤에서 밀어 M3 2개로 고정하며, 교체는 커버만 빼면 됩니다.

## 3. 목과 머리

1. **목 튜브** `neck_link` — 세로로 쌓인 목 피치·머리 피치 서보를 감싸는 사각 튜브. 혼이 나오는 +Y 쪽이 열려 있습니다.
2. **목 커버** `neck_sleeve` — 튜브 위에 씌우는 둥근 쉘. 목과 함께 기울어지며 몸통 슬롯 안에서 움직입니다.
3. **머리 베이스** `head_base` — 머리 피치 혼 판과 머리 요 혼 판. 머리가 요 회전해도 이 부품만 고정입니다.
4. **요크** `head_yoke` — 머리 요 서보를 담는 상자 + 머리 롤 혼 판까지 잇는 리브 2개.
5. **머리 프레임** `head_frame` — 한 덩이 쉘. 요크 위를 지나는 데크(z 261…263.4), 뒤 벽, 머리 롤 서보 벽, 턱 서보 행어, 앞쪽 빔(x 40.5…60)과 기둥(x 51…55), 카메라 벽(x 56…60, CM3급 홀 Y ±10.5 / Z 233.85·246.35), 두개골 보스 3개. 카메라를 micro-x보다 10 mm 뒤로 옮겨 두개골을 짧고 둥글게 만들었고, 그 대가로 코 보어가 14 mm 깔때기가 되어 **실효 화각이 약 60°로 모듈 정격보다 좁습니다**. 빔과 앞쪽 보스는 요크 앞면(x 39.4)에서 2 mm 이상 떨어져야 합니다 — 여기 닿으면 머리 롤이 0°가 됩니다.
6. **두개골** `skull` — 단면 9개의 둥근 로프트 + 짧은 입 타원체. 아래와 뒤가 열려 있고, 코 자리에 렌즈 후드(Ø18, x 68…74)가 있습니다. **귀는 별도 부품이 아니라 지붕에서 자라난 통짜 핀**(밑동 x 6 근처, |y| 34, z 276에서 시작해 z 310까지)이라 부러질 목이 없습니다. **눈도 부품이 아니라 쉘과 한 몸인 Ø23 버튼**이고, 눈동자·귀 안쪽·코는 도색입니다. M3 3개로 프레임 보스에 위에서 체결합니다.
7. **아래턱** `jaw_chin` — 턱 서보 혼에 붙는 팔 하나와 둥근 턱 컵. 입 개구(x 42…82)를 덮습니다. 가동 범위는 요크 앞면(x 39.4)에 걸려 좁습니다 — 실측값은 `engineering/joint_travel.json`.

## 검증 상태와 남은 확인

- 설계 자세 정적 간섭 0건, 측정 가동 범위 안 관절별 샘플 충돌 0건 (`artifacts/interference.json`). 가동 범위는 `tools/travel.py`가 측정한 값이며 `engineering/joint_travel.json`에 있습니다.
- 미검증: 출력 공차, 서보 케이스 고정, 케이블 경로(목·머리 4축과 다리 5축), IMU·마이크·스피커·전원 보드, 낙하·피로·발열, 실제 보행.
- 출력 순서 권장: 시편 → 발·종아리·허벅지 한 세트 → 고관절 브래킷 → 몸통 → 머리.

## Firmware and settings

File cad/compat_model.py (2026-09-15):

"""Micro Cat Rev 1 14-axis MuJoCo model, generated from the cat CAD.

Bodies, pivots and axes follow cad/layout.py (design pose = qpos 0, so no joint `ref`
offsets are needed and the policy HOME angles are ordinary joint targets). Masses and
inertias come from the printed-part meshes at PLA solid density plus purchased envelopes
with catalogue masses. Names the pinned inference adapter needs are kept: body
trunk_base, freejoint trunk_base_freejoint, site imu, the 14 joint/actuator names.
"""
from pathlib import Path
import json,sys,xml.etree.ElementTree as E
import numpy as np,trimesh,mujoco
R=Path(__file__).resolve().parents[1];sys.path.insert(0,str(R/'cad'))
import layout as L
DENSITY=1240.0
# Joint limits are the measured collision-free travel of the printed parts (tools/travel.py),
# not a wish list: the model can only command what the mechanism can actually do.
TRAVEL=json.loads((R/'engineering/joint_travel.json').read_text())['joints']
def vector(v):return ' '.join(f'{x:.9g}' for x in np.asarray(v,float))
def add(p,tag,**kw):return E.SubElement(p,tag,{k:str(v) for k,v in kw.items()})
def inertia_of(meshes):
    total=sum(m for m,_ in meshes);com=sum(m*me.center_mass for m,me in meshes)/total;I=np.zeros((3,3))
    for m,me in meshes:
        props=me.mass_properties;ratio=m/props['mass'] if props['mass']>0 else 0;d=me.center_mass-com
        I+=props['inertia']*ratio+m*(np.eye(3)*np.dot(d,d)-np.outer(d,d))
    return total,com,I
def build():
    report=json.loads((R/'artifacts/parts.json').read_text())
    pivots={b:(L.JOINT_OF_BODY[b]['P'] if b in L.JOINT_OF_BODY else L.TRUNK_ORIGIN) for b in L.BODIES}
    per_body={b:[] for b in L.BODIES};extents={};soles={}
    for p in report['parts']+report['purchased']:
        mesh=trimesh.load_mesh(R/(('models/'+p['name']+'.stl') if p['printed'] else p['stl']));mesh.vertices=(mesh.vertices-pivots[p['body']])*.001
        mass=(mesh.volume*DENSITY if p['printed'] else p['mass_g']*.001)
        if not p['printed']:
            lo,hi=mesh.bounds;mesh=trimesh.creation.box(hi-lo);mesh.apply_translation((lo+hi)/2)
        per_body[p['body']].append((mass,mesh));extents.setdefault(p['body'],[]).append(mesh.bounds)
        if p['name'].endswith('_foot'):
            # Two contact patches measured from the printed paw, not declared: the flat sole,
            # and the heel spur that sits above it and only reaches the floor once the robot
            # has pitched back. Keeping them separate is what stops the spur from enlarging
            # the walking contact patch, which is what kills commanded yaw.
            v=mesh.vertices;z=v[:,2];z0=z.min()
            sole=v[z<=z0+.0005]
            rear=v[(v[:,0]<sole[:,0].min())&(z<=z0+.004)]
            patches=[(sole.min(axis=0),sole.max(axis=0),'sole')]
            if len(rear):
                s0=rear[:,2].min();spur=rear[rear[:,2]<=s0+.0005]
                patches.append((spur.min(axis=0),spur.max(axis=0),'spur'))
            soles[p['body']]=patches
    r=E.Element('mujoco',model='Micro_Cat_Rev1_14');add(r,'compiler',angle='radian',autolimits='true');add(r,'option',timestep='.005',gravity='0 0 -9.81',iterations=80)
    default=add(r,'default');add(default,'joint',damping='.02',armature='.00001',frictionloss='.005');add(default,'geom',friction='1 .005 .0001',condim='3')
    w=add(r,'worldbody');add(w,'geom',name='floor',type='plane',size='3 3 .01',rgba='.85 .85 .8 1')
    xml={};qpos_order=[]
    def body_xml(b):
        parent=L.PARENT[b]
        if parent is None:
            el=add(w,'body',name='trunk_base',pos=vector(L.TRUNK_ORIGIN*.001));add(el,'freejoint',name='trunk_base_freejoint');add(el,'site',name='imu',size='.003',pos='-0.01 0 0.135')
        else:
            j=L.JOINT_OF_BODY[b];el=add(xml[parent],'body',name='x_'+b,pos=vector((pivots[b]-pivots[parent])*.001))
            lo,hi=TRAVEL[j['name']]['min_rad'],TRAVEL[j['name']]['max_rad']
            extra={'stiffness':'.05'} if j['name']=='jaw' else {}
            add(el,'joint',name=j['name'],axis=vector(j['axis']),range=f'{lo} {hi}',**extra);qpos_order.append(j['name'])
        mass,com,I=inertia_of(per_body[b])
        add(el,'inertial',pos=vector(com),mass=f'{mass:.6g}',fullinertia=vector([I[0,0],I[1,1],I[2,2],I[0,1],I[0,2],I[1,2]]))
        xml[b]=el
        for c in [c for c in L.BODIES if L.PARENT[c]==b]:body_xml(c)
    body_xml('trunk')
    def box_geom(b,name,lo,hi,**kw):
        lo=np.asarray(lo);hi=np.asarray(hi);add(xml[b],'geom',name=name,type='box',pos=vector((lo+hi)/2),size=vector((hi-lo)/2),mass='0',rgba='.8 .3 .1 .25',group='3',**kw)
    for side in ['left','right']:
        g=1 if side=='left' else -1;p=pivots[f'{side}_foot']
        for lo,hi,kind in soles[f'{side}_foot']:
            name=f'{side}_foot_collision' if kind=='sole' else f'{side}_foot_spur_collision'
            box_geom(f'{side}_foot',name,lo,[hi[0],hi[1],lo[2]+(.0105 if kind=='sole' else .004)])
            if kind=='sole':
                add(xml[f'{side}_foot'],'site',name=f'{side}_foot',pos=vector([(lo[0]+hi[0])/2,(lo[1]+hi[1])/2,lo[2]]),size='.003')
        for b in [f'{side}_upper_leg',f'{side}_lower_leg']:
            lo=np.min([e[0] for e in extents[b]],axis=0);hi=np.max([e[1] for e in extents[b]],axis=0);box_geom(b,b+'_collision',lo,hi,contype='2',conaffinity='2')
    add(xml['trunk'],'geom',name='trunk_shell_collision',type='ellipsoid',pos=vector((np.array([-6,0,142])-L.TRUNK_ORIGIN)*.001),size='.044 .0376 .024',mass='0',rgba='.8 .3 .1 .25',group='3',contype='1',conaffinity='1')
    add(xml['head'],'geom',name='head_shell_collision',type='ellipsoid',pos=vector((np.array([10,0,247])-pivots['head'])*.001),size='.062 .055 .033',mass='0',rgba='.8 .3 .1 .25',group='3',contype='1',conaffinity='1')
    contacts=add(r,'contact')
    for a,b in [('trunk_base','x_head'),('x_left_upper_leg','x_right_upper_leg'),('x_left_lower_leg','x_right_lower_leg')]:add(contacts,'exclude',body1=a,body2=b)
    act=add(r,'actuator')
    for name in L.ORDER:add(act,'position',name=name,joint=name,kp='5',ctrlrange='-2.4 2.4',forcerange='-.5 .5')
    sensors=add(r,'sensor');add(sensors,'gyro',name='imu_ang_vel',site='imu');add(sensors,'accelerometer',name='imu_accel',site='imu');add(sensors,'subtreeangmom',name='root_angmom',body='trunk_base')
    E.indent(r);E.ElementTree(r).write(R/'models/micro_cat_14.xml',encoding='unicode')
    # Standing height at HOME: the absolute trunk height that puts the lowest foot corner on the floor.
    m=mujoco.MjModel.from_xml_path(str(R/'models/micro_cat_14.xml'));d=mujoco.MjData(m)
    for i,name in enumerate(qpos_order):
        d.qpos[7+i]=L.HOME[name]
    mujoco.mj_forward(m,d)
    low=min(d.geom_xpos[mujoco.mj_name2id(m,mujoco.mjtObj.mjOBJ_GEOM,f'{s}_foot_collision')][2]-m.geom_size[mujoco.mj_name2id(m,mujoco.mjtObj.mjOBJ_GEOM,f'{s}_foot_collision')][2] for s in ['left','right'])
    # A free joint's qpos[:3] is the absolute body position, so this is a height, not an offset.
    home_z=round(float(L.TRUNK_ORIGIN[2]*.001-low+.001),5)
    total=sum(inertia_of(per_body[b])[0] for b in L.BODIES)
    (R/'engineering/control_interface.json').write_text(json.dumps(dict(joint_names=L.ORDER,home_rad=[L.HOME[n] for n in L.ORDER],observation_size=61,action_size=14,command_size=13,control_hz=50,physics_hz=200,action_scale=1,
        actuator_target='XL330 / BAM M6; assumed kp 200, 7.4 V',geometry='Rev B CAD-derived bodies in the design pose: printed-part meshes at PLA solid density plus purchased envelopes with catalogue masses',
        functional_dimensions='engineering/functional_layout.json',joint_ranges_rad={n:[TRAVEL[n]['min_rad'],TRAVEL[n]['max_rad']] for n in L.ORDER},joint_ranges_source='engineering/joint_travel.json (measured)',
        model_mass_kg=round(total,4),home_trunk_z_m=home_z,physical_verified=False),indent=2)+'\n')
    rig=dict(units='m',root='trunk',root_position_m=list(np.round(L.TRUNK_ORIGIN*.001+np.array([0,0,home_z]),6)),qpos_layout=dict(free=7,joints=qpos_order),
        bodies=[dict(name=b,parent=L.PARENT[b],pivot_m=np.round(pivots[b]*.001,6).tolist(),joint=(L.JOINT_OF_BODY[b]['name'] if b in L.JOINT_OF_BODY else None),
                     axis=(np.round(np.asarray(L.JOINT_OF_BODY[b]['axis'],float)/np.linalg.norm(L.JOINT_OF_BODY[b]['axis']),6).tolist() if b in L.JOINT_OF_BODY else None),
                     home_rad=(L.HOME[L.JOINT_OF_BODY[b]['name']] if b in L.JOINT_OF_BODY else None),mass_kg=round(inertia_of(per_body[b])[0],5)) for b in L.BODIES],
        policy_joints=L.ORDER,mass_kg=round(total,4))
    (R/'models/rig.json').write_text(json.dumps(rig,indent=1)+'\n')
    print(f'Built Rev 1 14-axis model, mass {total*1000:.0f} g, HOME trunk height {home_z*1000:.1f} mm')
if __name__=='__main__':build()

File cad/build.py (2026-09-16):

"""Micro Cat Rev 1: actuated chibi cat, built in the straight-leg design pose.

World frame: X forward, Y left, Z up, mm. Joint pivots, axes and servo placements come
from engineering/functional_layout.json (measured functional dimensions); every part
around them is original. Each servo is held by a U-channel in one link and drives a
single horn plate on the next, the way the reference robot does it - no clevis
sandwiches - so every part is a thin prismatic shell that prints flat without support.
NOT a physically validated or production-released robot.
"""
from pathlib import Path
import json, math, os, sys
import cadquery as cq
import numpy as np
import trimesh
sys.path.insert(0,str(Path(__file__).resolve().parent))
import layout as L
import servo as S
from appearance import paint
R=Path(__file__).resolve().parents[1]
for folder in ['models/step','models/print','artifacts','models/purchased']:(R/folder).mkdir(parents=True,exist_ok=True)
SHELL=[.96,.94,.90,1];ACCENT=[.97,.66,.62,1];GRAPHITE=[.22,.25,.26,1];DARK=[.12,.14,.15,1] # SHELL = warm off-white body, ACCENT = pink nose / paw pads / inner ear
DENSITY=0.00124 # g/mm3 PLA solid-equivalent; slicer mass with infill is lower
WALL=3.0 # shell wall; raised from 2.4 for drop strength
ROLL_SWEEP=0.35 # rad of hip-roll clearance carved into the hip bracket
SPUR_LIFT=1.0   # mm the heel spur sits above the sole plane; it must clear the floor while walking
SPUR_BACK=-86   # mm; the spur must reach the floor BEFORE the sole-only tipping angle (4.75 deg),
                # so the setback from the sole's rear edge has to exceed SPUR_LIFT/tan(4.75 deg) = 18 mm
parts=[];purchased=[]

def box(x0,x1,y0,y1,z0,z1):return cq.Workplane('XY').box(x1-x0,y1-y0,z1-z0).translate(((x0+x1)/2,(y0+y1)/2,(z0+z1)/2))
def rbox(x0,x1,y0,y1,z0,z1,r):return box(x0,x1,y0,y1,z0,z1).edges().fillet(min(r,(x1-x0)/2-.01,(y1-y0)/2-.01,(z1-z0)/2-.01))
def vbox(x0,x1,y0,y1,z0,z1,r):return box(x0,x1,y0,y1,z0,z1).edges('|Z').fillet(min(r,(x1-x0)/2-.01,(y1-y0)/2-.01)) # flat top and bottom: prints on its face
def ell(c,h):return cq.Workplane(obj=cq.Workplane('XY').sphere(1).val().transformGeometry(cq.Matrix([[h[0],0,0,c[0]],[0,h[1],0,c[1]],[0,0,h[2],c[2]]])))
def cyl(p,axis,r,length):return cq.Workplane({'Z':'XY','Y':'XZ','X':'YZ'}[axis],origin=tuple(p)).circle(r).extrude(length)
def cone(p,axis,r0,r1,length):return cq.Workplane({'Z':'XY','Y':'XZ','X':'YZ'}[axis],origin=tuple(p)).circle(r0).workplane(offset=length).circle(r1).loft()
def zloft(sections):
    """Ellipse wires stacked along Z: (z, x centre, y centre, half X, half Y)."""
    return cq.Workplane(obj=cq.Solid.makeLoft([cq.Workplane('XY',origin=(x,y,z)).ellipse(a,b).val() for z,x,y,a,b in sections],ruled=False))
def curve_loft(nodes):
    """Ellipse wires on planes normal to the local centreline tangent: (x, z, half Y, half depth)."""
    P=np.array([[n[0],n[1]] for n in nodes],float);wires=[]
    for i,(x,z,a,b) in enumerate(nodes):
        t=P[min(i+1,len(P)-1)]-P[max(i-1,0)];t=t/np.linalg.norm(t)
        plane=cq.Plane(origin=(x,0,z),xDir=(0,1,0),normal=(float(t[0]),0.,float(t[1])))
        wires.append(cq.Workplane(plane).ellipse(a,b).val())
    return cq.Workplane(obj=cq.Solid.makeLoft(wires,ruled=False))
def keep_solid(shape,name):
    shape=shape.clean();solids=shape.solids().vals()
    if len(solids)!=1:
        big=max(solids,key=lambda s:s.Volume());small=sum(abs(s.Volume()) for s in solids if s is not big)
        # abs() matters: a failed boolean can leave an inverted solid whose negative volume
        # cancelled the sum and let a 1.7 kg broken tail through this guard unnoticed.
        if small>200:raise ValueError(f'{name}: {len(solids)} solids, {small:.1f} mm3 loose')
        for sl in solids:
            if sl is not big:bb=sl.BoundingBox();print(f'  WARNING {name}: dropped {sl.Volume():.1f} mm3 sliver at x {bb.xmin:.1f}..{bb.xmax:.1f} y {bb.ymin:.1f}..{bb.ymax:.1f} z {bb.zmin:.1f}..{bb.zmax:.1f}')
        shape=cq.Workplane(obj=big)
    if not shape.val().isValid():raise ValueError(name+' invalid solid')
    return shape
ROT={'Z':None,'-Z':(math.pi,[1,0,0]),'Y':(math.pi/2,[1,0,0]),'-Y':(-math.pi/2,[1,0,0]),'X':(math.pi/2,[0,1,0]),'-X':(-math.pi/2,[0,1,0])}
def add(name,shape,color,body,print_axis='Z',note='',group='frame'):
    # Re-open every horn bolt path this link owns. Ribs and shells unioned on top of a horn
    # plate silently fill its holes, and a plate you cannot bolt is not a plate.
    for s in L.plates_on(body):
        tool=S.horn_holes(s['P'],s['h'],s['d'])
        a=shape.val().BoundingBox();c=tool.val().BoundingBox()
        if any(getattr(a,k+'max')<getattr(c,k+'min')-.5 or getattr(c,k+'max')<getattr(a,k+'min')-.5 for k in 'xyz'):continue
        shape=shape.cut(tool)
    shape=keep_solid(shape,name)
    path=R/'models/step'/f'{name}.step';cq.exporters.export(shape,str(path))
    restored=cq.importers.importStep(str(path))
    if len(restored.solids().vals())!=1 or not restored.val().isValid():raise ValueError(name+' STEP round trip lost valid solid')
    stl=R/'models'/f'{name}.stl';cq.exporters.export(shape,str(stl),tolerance=.05,angularTolerance=.1)
    mesh=trimesh.load_mesh(stl,process=True);mesh.merge_vertices(digits_vertex=6);mesh.update_faces(mesh.nondegenerate_faces());mesh.remove_unreferenced_vertices()
    if not mesh.is_watertight:
        cq.exporters.export(shape,str(stl),tolerance=.1,angularTolerance=.2);mesh=trimesh.load_mesh(stl,process=True);mesh.merge_vertices(digits_vertex=5);print('  retessellated',name)
    mesh.export(stl)
    if not mesh.is_watertight or mesh.volume<=0:raise ValueError(name+' mesh invalid')
    printable=mesh.copy()
    if ROT[print_axis]:printable.apply_transform(trimesh.transformations.rotation_matrix(*ROT[print_axis]))
    printable.vertices-=np.r_[printable.bounds.mean(axis=0)[:2],printable.bounds[0,2]];printable.export(R/'models/print'/f'{name}.stl')
    vol=shape.val().Volume()
    parts.append(dict(name=name,shape=shape,mesh=mesh,color=color,body=body,group=group,note=note,printed=True,print_axis=print_axis,
        dimensions_mm=np.round(mesh.extents,2).tolist(),volume_mm3=round(vol,1),mass_g=round(vol*DENSITY,2),step=f'models/step/{name}.step',stl=f'models/print/{name}.stl'))
    print(f'  {name:22s} {vol*DENSITY:7.1f} g')
    return shape
def buy(name,shape,color,body,mass_g,note,kind):
    shape=keep_solid(shape,name)
    stl=R/'models/purchased'/f'{name}.stl';cq.exporters.export(shape,str(stl),tolerance=.08,angularTolerance=.15)
    mesh=trimesh.load_mesh(stl,process=True);mesh.export(stl)
    purchased.append(dict(name=name,shape=shape,mesh=mesh,color=color,body=body,kind=kind,mass_g=mass_g,note=note,printed=False,
        dimensions_mm=np.round(mesh.extents,2).tolist(),stl=f'models/purchased/{name}.stl'))
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

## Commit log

2026-09-15 Micro Cat Rev 1: commercial cat biped on the measured design-pose toolchain
    New repository. Carries over micro-x's design pose (qpos 0), single-sided servo
    mounting and measurement tools; no Microduck hardware files.
    Cat geometry:
    - round cranium loft + short muzzle, 108 x 110 x 62 mm; camera moved 10 mm back
    to shorten the head, which narrows the usable nose-bore field of view to ~60 deg
    - ears and eyes grown out of the shell, no parts that can snap off
    - tail curls up on tangent-plane sections and still covers the battery
    - paws reach 16 mm further back than the reference foot
    Measured, not declared:
    - backward tipping 4.7 deg (micro-x) -> 11.2 deg for +10 g; aft support was the
    weak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
    [battery_pack.stl, bom.csv, camera_module_3.stl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]
2026-09-15 Heel spur instead of a long sole, and calibrate the harness before trusting it
    Two findings changed the design.
    1. A longer sole is the wrong fix for backward tipping. tools/tip_study.py now
    rocks the body quasi-statically - rotate, drop to the floor, recompute the
    contact set - instead of projecting the centre of mass onto a fixed hull. That
    is what lets a raised heel spur count: it carries no load standing upright and
    becomes the pivot only after the robot has pitched back. The sole goes back to
    the reference 58 mm and a spur sits 1.0 mm above it, reaching 24 mm behind.
    Backward tipping 4.65 -> 14.55 deg. A 1.5 mm spur changes nothing at all
    (4.65 deg) because the rob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
    [bom.csv, chassis.step, head_base.step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]
2026-09-16 README renders, and two paint bugs plus a heel spur sitting on a cliff
    The README had no picture at all. Adding one from the real CAD (tools/portrait.mjs
    photographs the shipped viewer, so the image cannot drift from the geometry) showed
    three things that were wrong in the model, not in the render.
    Paint, both the same failure: a mask whose region is larger than the surface's
    vertices can carry.
    - The eye button's flat face is tessellated from its rim only, so the 4 mm glint
    mask caught part of that rim and interpolated white across the whole disc. The
    eye rendered as a cream blob inside a dark ring. There is no glint now.
    - The eye face sat at |y| 52 where the skull's own half width is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
    [bom.csv, chassis.step, head_base.step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]
2026-09-16 Four defects that only a dedicated screen finds, and the screens that find them
    tools/fasteners.py walks each horn bolt axis and checks the path is open. Counting
    holes was not enough and neither was reading the drawing: both hip brackets had
    ZERO open bolt holes and each foot had one of four, because the ribs unioned onto a
    horn plate fill its holes. Those parts could not be fastened to their servos at all.
    add() now re-cuts every horn bolt path after the link is assembled.
    tools/strength.py checks each plate against its own servo's stall torque in closed
    form. It caught the jaw plate at safety factor 0.00: narrowed to 13 mm to chase jaw
    travel, its bolt holes ran off the plate edge with -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
    [bom.csv, chassis.step, chassis.stl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]
2026-09-16 Beat the reference robot on static stability, and say what it still loses
    Measured with one tool, one pose, all three models. Backward tipping: reference 8.5
    deg, Micro Cat 17.7. Forward 13.25 vs 19.25. Lateral 23.8 vs 25.25. Centre of mass
    5.4 mm lower. It costs 135 g, 18 % heavier than the reference.
    The tool had to be fixed first. It returned 0.0 degrees of forward tipping for the
    reference robot, which looked like a bug and was not: that robot's sole is not flat
    at HOME, it rests on a heel line with its centre of mass 21 mm ahead of it, and a
    rigid body there pitches forward until the toe lands. Tipping is now scored from the
    settled orientation, not from the nominal pose, or the refere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
    [chassis.step, chassis.stl, compute_board.stl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]
2026-09-17 Tried to grow the trunk around the chosen board; it made the robot worse, reverted
    The Radxa Zero 3W is 65 x 30 mm and the trunk's largest free rectangle at the deck
    plane is 34 x 49, so I widened the body to 104 x 104 and it did fit. Then:
    - the thigh spans y 43-75 and the widened body reached y 52, so the hip pitch sweep
    ran into the flank. Carving the real swept volume out of the shell cleared the
    collision and removed most of the lower side of the body with it.
    - raising the dome to fix the saucer shape that left split the shell into two solids.
    Reverted to 90 x 77. What the detour established is worth keeping: the neck column
    runs vertically through the middle of the trunk, so a 6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
    [bom.csv, chassis.step, head_base.step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]
